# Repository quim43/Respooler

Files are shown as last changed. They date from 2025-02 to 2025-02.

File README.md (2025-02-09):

#Respooler



🚀 **Respooler** es una máquina compacta para rebobinar filamento de impresora 3D de manera eficiente. Está basada en el diseño **V-Spooler**, pero con mejoras como un **motor paso a paso** y un **sensor de filamento** para facilitar su uso.

## 📌 Características

- Diseño compacto y optimizado.
- Soporte para diferentes poleas y correas HDT de 10 mm.
- Motor con ajuste fácil de tensión de correa.
- Eje de bobina más grueso para mayor resistencia.
- Compatible con **Maker's Supply**.
- Sensores que detienen el motor automáticamente cuando se completa el proceso.

## 🛠️ Hardware y Electrónica Necesaria

- Motor **NEMA 17**.
- Sensor de filamento.
- **Arduino Nano** para el control.
- Driver de motor paso a paso.
- Varias piezas impresas en 3D (recomendado **PETG o ABS** para mayor resistencia).
- Tornillos y soportes mecánicos.

Para comprar kits de hardware, visita: [LTS-Design Shop](https://lts-design.com/)

## 🔧 Ensamblaje

1. Instala la base del motor y fija el **NEMA 17** con tornillos M3 x 6.
2. Inserta tu **PCB** (si tienes el kit) y conecta el driver de motor.
3. Conecta los cables del **sensor de filamento** y **botón de inicio** a la PCB.
4. Asegura el regulador de potencia y ajusta la tensión si es necesario.
5. Ensambla el **soporte de la bobina** y el **sistema de poleas**.
6. Ajusta la correa y alinea los engranajes correctamente.
7. Carga el código en el Arduino desde la sección de **Documentación**.

📜 **Diagrama de conexión** disponible en la sección de documentación.

## 📹 Video en Acción

Mira el LTS Respooler en funcionamiento: [YouTube](https://youtu.be/B1Um_I1KRLo)

## ⚙️ Cómo Usarlo

1. Alimenta el filamento desde la bobina superior a través del tubo **PTFE**.
2. El LED derecho se encenderá (si no hay filamento, el motor no inicia).
3. Sujeta el filamento en la bobina inferior y presiona el **botón de inicio**.
4. El motor girará automáticamente hasta completar el proceso.
5. Para detener manualmente, presiona el botón nuevamente.

## 📜 Notas de Impresión 3D

- Las piezas negras deben imprimirse con **PETG o ABS** para mayor durabilidad.
- Algunas piezas requieren **soportes** que deben ser removidos tras la impresión.
- Los tornillos se ajustan directamente en el plástico (sin inserts), ¡no los aprietes demasiado!

## 🏪 Dónde Comprar Kits y Electrónica

Para facilitar la construcción, puedes adquirir diferentes kits en:

🔗 [LTS-Design Store](https://lts-design.com/)

- **PCB solo**: [Comprar aquí](https://lts-design.com/products/lts-respooler-pcb)
- **PCB + Electrónica**: [Comprar aquí](https://lts-design.com/products/lts-respooler-pcb-and-electronics)
- **Power Pack Completo**: [Comprar aquí](https://lts-design.com/products/lts-respooler-power-pack)

## 🛠️ Mejoras y Versiones

### 🔹 V3
- Soporte para **Maker's Supply**.
- Compatibilidad con **correas HDT de 10 mm**.
- Eje de bobina más grueso.
- Ajuste mejorado de la tensión del motor.

### 🔹 V2
- Nuevo diseño de base y estructura para mejor impresión.

### 🔹 V1.5
- Caja de electrónica rediseñada para **mejor ventilación** y menos soportes.

### 🔹 V1
- **Montura de motor ajustable**.

---

📌 **Este proyecto es de código abierto**. Si tienes mejoras, pull requests son bienvenidas. ¡Felices rebobinados! 🎉

---

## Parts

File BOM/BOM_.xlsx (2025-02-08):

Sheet: BOM Respooler
LCSC Part Number | Manufacture Part Number | Manufacturer | Package | Customer # | Description | RoHS | Order Qty. | Product Link
C2932676 | KH-2.54FH-1X15P-H8.5 | Shenzhen Kinghelm Elec | Plugin,P=2.54mm | U1,U2 | 2.54mm Single Row 3A 15P -40℃~+105℃ Direct Insert 1x15P 8.5mm Top Square Hole Plugin,P=2.54mm Female Headers ROHS | yes | 2.00 | https://www.lcsc.com/product-detail/female-headers_shenzhen-kinghelm-elec-kh-2-54fh-1x15p-h8-5_C2932676.html
C25091 | 0402WGF2200TCE | UNI-ROYAL(Uniroyal Elec) | 0402 | R4,R5 | 62.5mW Thick Film Resistors 50V ±100ppm/℃ ±1% 220Ω 0402 Chip Resistor - Surface Mount ROHS | yes | 2.00 | https://www.lcsc.com/product-detail/chip-resistor-surface-mount_uni-royal-uniroyal-elec-0402wgf2200tce_C25091.html
C218370 | ARG05FTC1742N | Viking Tech | 0805 | R2 | 125mW Thin Film Resistor 100V ±25ppm/℃ ±1% 17.4kΩ 0805 Chip Resistor - Surface Mount ROHS | yes | 1.00 | https://www.lcsc.com/product-detail/chip-resistor-surface-mount_viking-tech-arg05ftc1742n_C218370.html
C104683 | RTT062001FTP | RALEC | 1206 | R3 | 250mW Thick Film Resistors 150V ±100ppm/℃ ±1% 2kΩ 1206 Chip Resistor - Surface Mount ROHS | yes | 1.00 | https://www.lcsc.com/product-detail/chip-resistor-surface-mount_ralec-rtt062001ftp_C104683.html
C168095 | FNR6045S101MT | cjiang (Changjiang Microelectronics Tech) | SMD,6x6mm | L1 | 880mA 100uH ±20% 1A SMD,6x6mm Power Inductors ROHS | yes | 1.00 | https://www.lcsc.com/product-detail/power-inductors_cjiang-changjiang-microelectronics-tech-fnr6045s101mt_C168095.html
C476766 | C0805B104K500NT | TORCH | 0805 | C1 | 50V 100nF X7R ±10% 0805 Multilayer Ceramic Capacitors MLCC - SMD/SMT ROHS | yes | 1.00 | https://www.lcsc.com/product-detail/multilayer-ceramic-capacitors-mlcc-smd-smt_torch-c0805b104k500nt_C476766.html
C84983 | RSX301L-30TE25 | ROHM Semicon | SMA(DO-214AC) | D1 | 30V 420mV@3A 3A SMA(DO-214AC) Schottky Diodes ROHS | yes | 1.00 | https://www.lcsc.com/product-detail/schottky-diodes_rohm-semicon-rsx301l-30te25_C84983.html
C273671 | 08053C334K4Z2A | Kyocera AVX | 0805 | C2 | 25V 330nF X7R ±10% 0805 Multilayer Ceramic Capacitors MLCC - SMD/SMT ROHS | yes | 1.00 | https://www.lcsc.com/product-detail/multilayer-ceramic-capacitors-mlcc-smd-smt_kyocera-avx-08053c334k4z2a_C273671.html
C25804 | 0603WAF1002T5E | UNI-ROYAL(Uniroyal Elec) | 0603 | R1 | 100mW Thick Film Resistors 75V ±100ppm/℃ ±1% 10kΩ 0603 Chip Resistor - Surface Mount ROHS | yes | 1.00 | https://www.lcsc.com/product-detail/chip-resistor-surface-mount_uni-royal-uniroyal-elec-0603waf1002t5e_C25804.html
C494815 | EEEFN1C681UP | PANASONIC | SMD | C3 | 680uF 16V 600mA@100kHz 160mΩ@100kHz ±20% SMD Aluminum Electrolytic Capacitors - SMD ROHS | yes | 1.00 | https://www.lcsc.com/product-detail/aluminum-electrolytic-capacitors-smd_panasonic-eeefn1c681up_C494815.html
C2905417 | KH-2.54FH-1X8P-H8.5 | Shenzhen Kinghelm Elec | Plugin,P=2.54mm | U4,U3 | 2.54mm Single Row 3A 8P -40℃~+105℃ Direct Insert 1x8P 8.5mm Top Square Hole Plugin,P=2.54mm Female Headers ROHS | yes | 2.00 | https://www.lcsc.com/product-detail/female-headers_shenzhen-kinghelm-elec-kh-2-54fh-1x8p-h8-5_C2905417.html
C22388458 | BX-PH2.0-2PZZ-R | Bossie | Plugin,P=2mm | LED1,LED2,PUL | 1x2P PH 1 2P 2mm Tin 2 -25℃~+85℃ Copper alloy Direct Insert Plugin,P=2mm Wire To Board Connector ROHS | yes | 3.00 | https://www.lcsc.com/product-detail/wire-to-board-connector_bossie-bx-ph2-0-2pzz-r_C22388458.html
C18077835 | BX-XH2.54-4PZZ | Bossie | Plugin,P=2.54mm | MOTOR,LCD | 1x4P 4P 1 XH Tin 2.54mm 4 -25℃~+85℃ Brass 3A Direct Insert Plugin,P=2.54mm Wire To Board Connector ROHS | yes | 2.00 | https://www.lcsc.com/product-detail/wire-to-board-connector_bossie-bx-xh2-54-4pzz_C18077835.html
C5374805 | WAFER-XH2.54-3PZZ | XUNPU | Plugin,P=2.5mm | ENDSTOP | 1x3P 3P 1 2.54mm 3 -25℃~+85℃ 2A Direct Insert Plugin,P=2.5mm Wire To Board Connector ROHS | yes | 1.00 | https://www.lcsc.com/product-detail/wire-to-board-connector_xunpu-wafer-xh2-54-3pzz_C5374805.html
C544697 | LM2577T-ADJ/NOPB | Texas Instruments | TO-220-5 | U17 | Boost type Adjustable 3A 1.23V~60V 3.5V~40V TO-220-5 DC-DC Converters ROHS | yes | 1.00 | https://www.lcsc.com/product-detail/dc-dc-converters_texas-instruments-lm2577t-adj-nopb_C544697.html
 |  |  |  | TRANSPORT | UPS 3 -5 DIES |  | 1.00
 |  |  |  | ALIEXPRES
----- | Arduino CH340 | Aliexpres | ----- | Arduino nano | Para nano Mini/tipo-c/Micro USB con cargador de arranque controlador rojo Compatible para Arduino CH340 controlador USB 16Mhz ATMEGA328PB | ----- | 1.00 | https://es.aliexpress.com/item/1005006128051481.html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
----- | 17HS4401S | Aliexpres | ----- | Motor | Motor paso a paso con Cable de 1m para impresora 3D CNC, Motor paso a paso de 42 fases, ángulo de paso de 0,9 grados, bajo ruido, 17HS4401S | ----- | 1.00 | https://es.aliexpress.com/item/1005007462616478.html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
----- | 3D 896F endstop | Aliexpres | ----- | ENDSTOP | Interruptor de límite de impresora 3D 896F, accesorios de placa principal, reinicio mecánico-táctil, Endstop | ----- | 2.00 | https://es.aliexpress.com/item/1005005654734137.html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
----- | TMC2209 V3.0 | Aliexpres | ----- | Motor driver | Controlador de Motor paso a paso TMC2209 V3.0, 5 piezas, con 3D disipador de calor para impresora, corriente de Micropasos, pico 2.8A para Reprap Ramps1.4 MKS Gen | ----- | 1.00 | https://es.aliexpress.com/item/1005005351333035.html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
----- | LCD | Aliexpres | ----- | Módulo LCD | Módulo LCD LCD1602 para arduino, pantalla verde azul/amarilla de 16x2 caracteres, PCF8574T PCF8574 IIC I2C, interfaz 5V, 1602 | ----- | 1.00 | https://www.aliexpress.com/gcp/300000512/nnmixupdatev3?productIds=1005006018109299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
----- | Bot | Aliexpres | ----- | Pulsador | Interruptor de botón de enclavamiento de Metal, accesorio redondo de encendido/apagado, impermeable, autoblocante, 4 pines, CC de 2 piezas, 12V/24V | ----- | 1.00 | https://www.aliexpress.com/gcp/300000512/nnmixupdatev3?productIds=1005006018109299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
 |  |  |  | BAMBU LAB
----- | FA003 | FA003 | ----- | FA003 | 4mm Stainless Steel Balls (10PCS) - FA003 | ----- | 1.00 | https://eu.store.bambulab.com/es-es/products/bolas-de-acero-inoxidable?variant=48740440605020
----- | EA028 | EA028 | ----- | EA028 | 608zz P5 Steel Deep Groove Ball Bearings (2PCS) - EA028 | ----- | 7.00 | https://eu.store.bambulab.com/es-es/products/high-performance-bearings?variant=48795653767516
----- | AB005 | AB005 | ----- | AB005 | M3 Carbon Steel Hex Nut (20PCS) - AB005 | ----- | 1.00 | https://eu.store.bambulab.com/es-es/products/hex-nut?variant=48722463129948
----- | AA036 | AA036 | ----- | AA036 | M3x6 SHCS Machine Screw (20PCS) - AA036 | ----- | 2.00 | https://eu.store.bambulab.com/es-es/products/tornillos-para-maquinas-con-cabeza-hueca-m3-shcs-1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
----- | AA159 | AA159 | ----- | AA159 | M3x10 SHCS Machine Screw (20PCS) - AA159 | ----- | 2.00 | https://eu.store.bambulab.com/es-es/products/tornillos-para-maquinas-con-cabeza-hueca-m3-shcs-1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
----- | AA039 | AA039 | ----- | AA039 | M3x16 SHCS Machine Screw (10PCS) - AA039 | ----- | 1.00 | https://eu.store.bambulab.com/es-es/products/tornillos-para-maquinas-con-cabeza-hueca-m3-shcs-1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
----- | EA013 | EA013 | ----- | EA013 | MR85zz Steel Deep Groove Ball Bearings (6PCS) - EA013 | ----- | 1.00 | https://eu.store.bambulab.com/es-es/products/micro-steel-deep-groove-ball-bearings?variant=48828597993820
----- | RD014 | RD014 | ----- | RD014 | HTD 408-3M-10 Timing Belt (1PCS) - RD014 | ----- | 2.00 | https://eu.store.bambulab.com/es-es/products/high-torque-drive-timing-belt?variant=48890105528668
----- | EA035 | EA035 | ----- | EA035 | 6001zz Steel Deep Groove Ball Bearings (2PCS) - EA035 | ----- | 1.00 | https://eu.store.bambulab.com/es-es/products/steel-deep-groove-ball-bearings-1?variant=48828599828828
 |  |  |  |  | TAX |  | 1.00

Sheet: Bost_Proto
LCSC Part Number | Manufacture Part Number | Manufacturer | Customer NO. | Package | Description | RoHS | Order Qty. | Min\Mult Order Qty. | Unit Price(€) | Order Price(€)
C2873969 | KM1E101M0611 | ROQANG | C1 | Plugin | 100uF 25V ±20% 142mA@120kHz Plugin Aluminum Electrolytic Capacitors - Leaded ROHS | YES | 50 | 50\50 | 174 | 87
C109713 | MPP334J2E1305125LC | SRD(Shenzhen Sincerity Tech) | C2 | Plugin | 330nF -40℃~+85℃ ±5% Plugin Polypropylene Film Capacitors (CBB) ROHS | YES | 10 | 10\10 | 516 | 52
C1498450 | EKZH250ETD681MJ16S | NCC(Nippon Chemi-Con) | C3 | Plugin | 680uF 25V 32mΩ ±20% 990mA@120Hz Plugin Aluminum Electrolytic Capacitors - Leaded ROHS | YES | 5 | 5\5 | 2599 | 130
C9119 | 1N5821RLG | onsemi | D1 | DO-201AD | 30V 500mV@3A 3A DO-201AD Schottky Diodes ROHS | YES | 12 | 1\1 | 3095 | 371
C908342 | SLT065125T101KTB | Sunltech Tech | L1 | Plugin | 100uH Magnetic ring inductance ±10% Plugin Color Ring Inductors / Through Hole Inductors ROHS | YES | 2 | 1\1 | 5297 | 106
C172660 | RN16T51742F | TA-I Tech | R2 | Plugin,D2.5xL4.7mm | Metal Film Resistors 17.4kΩ 166.667mW ±100ppm/℃ ±1% Plugin,D2.5xL4.7mm Through Hole Resistors ROHS | YES | 50 | 50\50 | 98 | 49

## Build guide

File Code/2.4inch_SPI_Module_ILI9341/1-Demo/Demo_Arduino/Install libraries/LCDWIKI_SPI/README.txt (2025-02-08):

This is a library for the SPI lcd display.
This library support these lcd controller:
ILI9325 
ILI9328 
ILI9341 
HX8357D 
HX8347G 
HX8347I 
ILI9486 
ST7735S 
SSD1283A

Check out the file of LCDWIKI SPI lib Requirements for our tutorials and wiring diagrams.

These displays use spi bus to communicate, 5 pins are required to interface (MISO is no need).

Basic functionally of this library was origianlly based on the demo-code of Adafruit GFX lib and Adafruit SPITFT lib.  

MIT license, all text above must be included in any redistribution

To download. click the DOWNLOADS button in the top right corner, rename the uncompressed folder LCDWIKI_SPI. Check that the LCDWIKI_SPI folder contains LCDWIKI_SPI.cpp and LCDWIKI_SPI.h

Place the LCDWIKI_SPI library folder your <arduinosketchfolder>/libraries/ folder. You may need to create the libraries subfolder if its your first library. Restart the IDE

Also requires the LCDWIKI_GUI library for Arduino. 
https://github.com/lcdwiki/LCDWIKI_gui

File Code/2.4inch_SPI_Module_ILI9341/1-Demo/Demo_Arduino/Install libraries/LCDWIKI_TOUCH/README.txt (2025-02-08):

This is a library for the touch screen.
This library support these touch IC:
HR2046
XPT2046
 
Check out the file of LCDWIKI TOUCH lib Requirements for our tutorials and wiring diagrams.

These touch screen use 4-wire spi to communicate, 5 pins are required to interface (Need to add the TP_IRQ pin).
Run the touch screen calibration program and put the calibration parameter into the file of cali_para.h after the calibration has passed.

MIT license, all text above must be included in any redistribution

To download. click the DOWNLOADS button in the top right corner, rename the uncompressed folder LCDWIKI_TOUCH. Check that the LCDWIKI_TOUCH folder contains LCDWIKI_TOUCH.cpp and LCDWIKI_TOUCH.h

Place the LCDWIKI_TOUCH library folder your <arduinosketchfolder>/libraries/ folder. You may need to create the libraries subfolder if its your first library. Restart the IDE

Also requires the LCDWIKI_GUI and LCDWIKI_KBV library for Arduino. 
https://github.com/lcdwiki/LCDWIKI_gui
https://github.com/lcdwiki/LCDWIKI_kbv

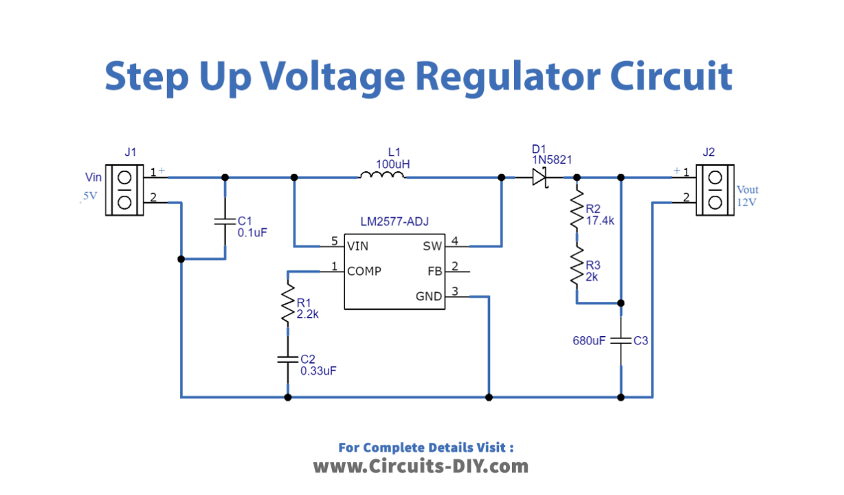
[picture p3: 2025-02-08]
Electronics/Step-Up-Voltage-Regulator-Circuit-IC-LM2577-diagram-schematic-1228x720-2.png

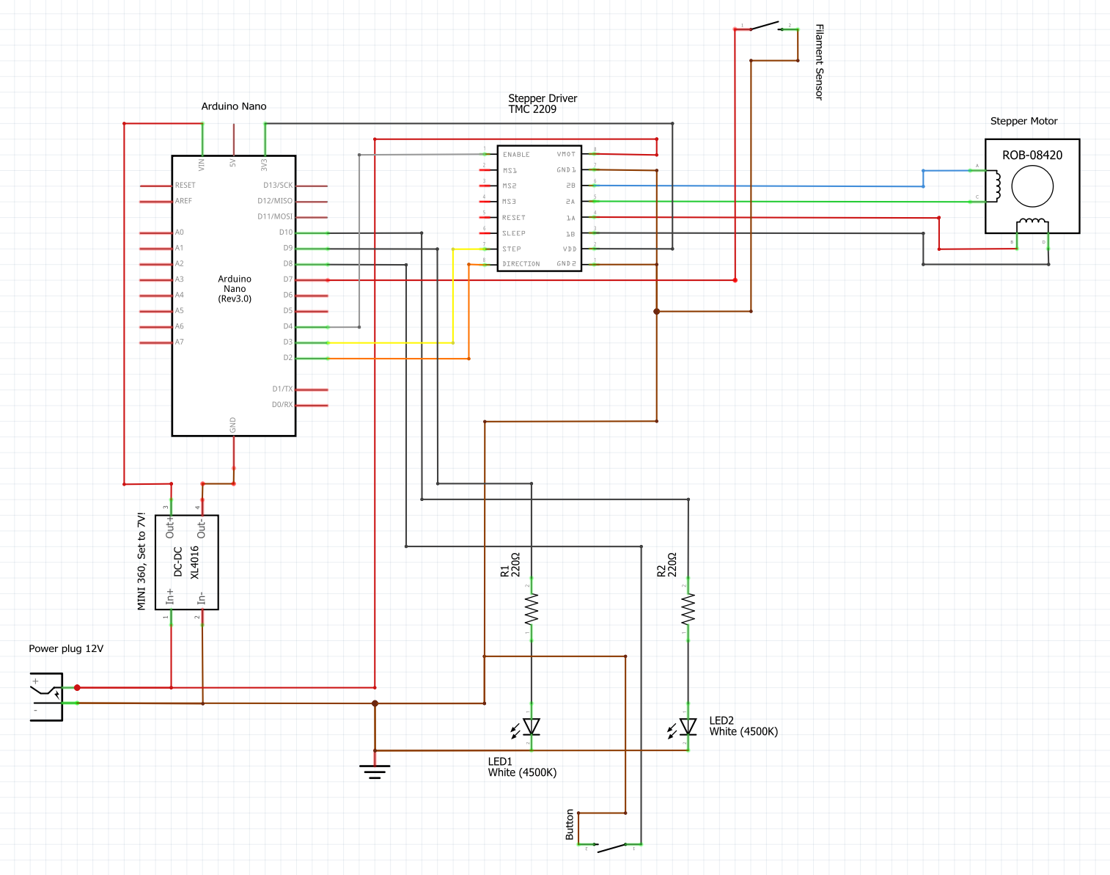
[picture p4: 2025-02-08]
Electronics/Wiring%20Diagram%20LTS%20Respooler.png

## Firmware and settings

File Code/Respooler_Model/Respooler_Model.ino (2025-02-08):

#include "SPI.h"
#include "Adafruit_GFX.h"
#include <AccelStepper.h>
#include "Adafruit_ILI9341.h"

// Pines del motor y LEDs
const int dirPin = 8;      // Pin de dirección del motor
const int stepPin = 9;     // Pin de pasos del motor
const int enablePin = 10;  // Pin de enable del driver
const int ledVerde = A1;   // LED verde (tensión OK)
const int ledBlanco = A1;  // LED blanco (motor funcionando)
const int pulsador = A2;   // Pulsador para activar el motor
const int endstop = 7;     // Endstop para detener el motor

// Crear objeto AccelStepper
AccelStepper motor(AccelStepper::DRIVER, stepPin, dirPin);

// Variables de estado
bool motorActivo = false;
unsigned long tiempoParpadeo = 0;             // Para controlar el parpadeo del LED blanco
const unsigned long intervaloParpadeo = 500;  // Intervalo de parpadeo (500ms)

// Pines para la pantalla TFT
#define TFT_CS A5       // Pin Chip Select
#define TFT_RST A4      // Pin Reset
#define TFT_DC A3       // Pin Data/Command
#define TFT_MOSI 11     // Pin MOSI para SPI
#define TFT_SCK 13      // Pin Clock para SPI
#define TFT_LED A0      // Pin para el backlight de la pantalla
#define TFT_MISO 12     // No usado para TFT
#define GFX_BL TFT_LED  // Pin para controlar el backlight

// Pines de conexión del controlador táctil XPT2046
#define T_CS    2    // Pin Chip Select del controlador táctil
#define T_IRQ   6    // Pin de interrupción del controlador táctil (opcional)

// Velocidad del SPI (reducida para mejor estabilidad)
#define SPI_SPEED 20000000  // 40 MHz (puedes probar valores más bajos si sigue habiendo problemas)

// Crear una instancia de la pantalla
// Adafruit_ILI9341 tft = Adafruit_ILI9341(TFT_CS, TFT_DC, TFT_RST);
Adafruit_ILI9341 tft = Adafruit_ILI9341(TFT_CS, TFT_DC, TFT_MOSI, TFT_SCK, TFT_RST, TFT_MISO);
// XPT2046_Touchscreen ts(T_CS, -1);  // No usar interrupciones para facilitar la calibración

void setup() {
  // Configuración de los pines del motor
  delay(500);
  //setCpuFrequencyMhz(240);

  pinMode(TFT_LED, OUTPUT);
  pinMode(ledVerde, OUTPUT);
  pinMode(ledBlanco, OUTPUT);
  pinMode(pulsador, INPUT_PULLUP);
  pinMode(endstop, INPUT_PULLUP);
  pinMode(enablePin, OUTPUT);  // Pin Enable del driver
  pinMode(dirPin, OUTPUT);     // Configurar dirPin como salida
  pinMode(stepPin, OUTPUT);    // Configurar stepPin como salida

  digitalWrite(TFT_LED, HIGH);

  // Inicializar la pantalla táctil

  // Encender el LED verde indicando que hay tensión
  digitalWrite(ledVerde, HIGH);

  // Desactivar el motor al inicio
  digitalWrite(enablePin, HIGH);  // Desactivar el driver (Enable es activo en LOW)

  // Configurar aceleración y velocidad del motor
  motor.setMaxSpeed(5000);     // Establecer velocidad máxima del motor
  motor.setAcceleration(200);  // Establecer aceleración del motor

  // Iniciar comunicación serie
  delay(800);
  Serial.begin(9600);
  Serial.println("Iniciando ILI9341...");

  // Añadir un pequeño retraso antes de inicializar la pantalla

  // Inicializar la pantalla con una velocidad SPI ajustada
  tft.begin(SPI_SPEED);

  // Añadir otro retraso después de la inicialización
  delay(500);

  // Establecer la rotación de la pantalla (opcional, 0 a 3)
  tft.setRotation(3);
  delay(500);
  // Rellenar la pantalla de negro
  tft.fillScreen(ILI9341_BLACK);

  // Dibujar un rectángulo de prueba
  // tft.fillRect(10, 10, 100, 50, ILI9341_RED);  // Un rectángulo rojo en la esquina superior izquierda
  delay(500);
  // Establecer el color del texto y el fondo
  tft.setTextColor(ILI9341_WHITE);  // Texto blanco
  tft.setTextSize(5);               // Tamaño de texto
  tft.setCursor(25, 100);
  tft.println("RESPOOLER");

  delay(500);
  tft.setTextColor(ILI9341_WHITE);  // Texto blanco
  tft.setTextSize(3);               // Tamaño de texto
  tft.setCursor(95, 160);
  tft.println("By Quim");
  delay(500);

  Serial.println("Prueba completada.");
}

void loop() {
  // Control del motor y LEDs
  if (digitalRead(pulsador) == LOW && digitalRead(endstop) == HIGH) {
    if (!motorActivo) {
      motorActivo = true;
      digitalWrite(enablePin, LOW);  // Activar el driver (Enable es activo en LOW)
      motor.setSpeed(-4000);         // Velocidad continua (ajusta según necesidad)
      digitalWrite(ledBlanco, LOW);  // Apagar LED blanco momentáneamente (inicia el parpadeo)
    }
    motor.runSpeed();      // El motor gira indefinidamente
    parpadearLedBlanco();  // El LED blanco parpadea mientras el motor funciona
    
  } else {
    if (motorActivo) {
      motorActivo = false;
      motor.stop();                   // Detener el motor
      digitalWrite(enablePin, HIGH);  // Desactivar el driver (Enable es activo en LOW)
      digitalWrite(ledBlanco, HIGH);  // LED blanco fijo indicando que el motor se ha detenido
    }
  }
}

// Función para parpadear el LED blanco
void parpadearLedBlanco() {
  unsigned long tiempoActual = millis();
  if (tiempoActual - tiempoParpadeo >= intervaloParpadeo) {
    tiempoParpadeo = tiempoActual;
    // Cambiar el estado del LED para hacer el efecto de parpadeo
    digitalWrite(ledBlanco, !digitalRead(ledBlanco));
  }
}

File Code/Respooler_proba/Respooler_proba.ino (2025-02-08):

#include "SPI.h"
#include "Adafruit_GFX.h"
#include <AccelStepper.h>
#include "Adafruit_ILI9341.h"
#include "XPT2046_Touchscreen.h"

// Incluir las imágenes
#include "bambu_lab.h"
#include "sunluxl.h"
#include "sunlu.h"
#include "rpbq.h"
#include "cb.h"
#include "c.h"

#define TFT_LED        A0
const int ledVerde =   A1;
const int ledBlanco =  A1;
const int pulsador =   A2;
#define TFT_DC         A3
#define TFT_RST        A4
#define TFT_CS         A5

#define T_CS           2
const int endstop =    7;
const int dirPin =     8;
const int stepPin =    9;
const int enablePin = 10;

// Configuración de SPI y pantalla
#define SPI_SPEED 20000000

Adafruit_ILI9341 tft = Adafruit_ILI9341(TFT_CS, TFT_DC, TFT_RST);
AccelStepper motor(AccelStepper::DRIVER, stepPin, dirPin);
XPT2046_Touchscreen ts(T_CS, -1);

// Variables de estado
bool motorActivo = false;
bool pantallaActiva = true; 
bool estadoPulsador = HIGH; // Estado actual del pulsador
bool estadoPulsadorAnterior = HIGH; // Estado anterior del pulsador

unsigned long tiempoParpadeo = 0;
const unsigned long intervaloParpadeo = 500;

String bobinaSeleccionada =   "";
String materialSeleccionado = "";

float longitudTotalFilamento = 0.0;
float densidadMaterial =       0.0;
float diametroInterno =        0.0;
float pesoFilamento =          0.0;
long pasosAcumulados =           0;

/*
###############################################
*/
void mostrarMensajeInicio() {
  pantallaActiva = true;
  longitudTotalFilamento = 0;
  pesoFilamento = 0;

  // Dibujar la imagen de inicio en la pantalla
  tft.fillScreen(ILI9341_BLACK);
  tft.drawRGBBitmap(0, 0, rpbq, 320, 240);
  // delay(3500);  // Pausa inicial para mostrar la imagen
  
  // Esperar hasta que no haya ningún toque detectado (por si queda alguno residual)
  while (ts.touched()) {
    delay(100);
  }

  // Esperar un toque para avanzar
  Serial.println("Esperando toque en la imagen...");
  while (!ts.touched()) {
    delay(100);  // Pausa breve para evitar un bucle continuo
  }

  delay(500);  // Pausa adicional para evitar toques repetidos
  cargarBobines();
}


void cargarBobines(){
  pantallaActiva = false;
  tft.fillScreen(ILI9341_BLACK);
  tft.drawRGBBitmap(0, 0, cb, 320, 240);
  while (digitalRead(pulsador) == HIGH){} // && digitalRead(endstop) == LOW 
  delay(500);
  pantallaActiva = true;
  mostrarMenuBobina();
  }

void mostrarMenuBobina() {
  tft.fillScreen(ILI9341_BLACK);
  tft.setTextColor(ILI9341_WHITE);
  tft.setTextSize(2);
  tft.setCursor(20, 20);
  tft.println("Selecciona una bobina:");
  tft.drawRGBBitmap(15, 80, bambu_lab, 90, 90);  // Imagen Bambu Lab
  tft.drawRGBBitmap(115, 80, sunlu, 90, 90);     // Imagen Sunlu
  tft.drawRGBBitmap(215, 80, sunluxl, 90, 90);   // Imagen Sunlu XL
  }

void manejarTouch(int x, int y) {
  if (x > 25 && x < 115 && y > 80 && y < 170) {
    bobinaSeleccionada = "Bambu Lab";
    diametroInterno = 55.0;
    seleccionarMaterial();
  } else if (x > 125 && x < 215 && y > 80 && y < 170) {
    bobinaSeleccionada = "Sunlu";
    diametroInterno = 54.4;
    seleccionarMaterial();
  } else if (x > 225 && x < 315 && y > 80 && y < 170) {
    bobinaSeleccionada = "Sunlu XL";
    diametroInterno = 7.25;
    seleccionarMaterial();
    }
  }

void seleccionarMaterial() {
  tft.fillScreen(ILI9341_BLACK);
  tft.setTextColor(ILI9341_WHITE);
  tft.setTextSize(2);
  tft.setCursor(20, 20);
  tft.println("Selecciona el material:");
  tft.setCursor(50, 80); tft.println("PLA");
  tft.setCursor(50, 140); tft.println("PETG");
  tft.setCursor(50, 200); tft.println("ABS");

  while (true) {
    if (ts.touched()) {
      TS_Point p = ts.getPoint();
      int x_mapped = map(p.x, 689, 3700, 0, 320);
      int y_mapped = map(p.y, 3418, 746, 0, 240);
      if (x_mapped > 50 && x_mapped < 150) {
        if (y_mapped > 80 && y_mapped < 120) { materialSeleccionado = "PLA"; densidadMaterial = 1.24; break; }
        else if (y_mapped > 140 && y_mapped < 180) { materialSeleccionado = "PETG"; densidadMaterial = 1.27; break; }
        else if (y_mapped > 200 && y_mapped < 240) { materialSeleccionado = "ABS"; densidadMaterial = 1.04; break; }
        }
      }
    }
    confirmarSeleccion();
  }

void confirmarSeleccion() {
  tft.fillScreen(ILI9341_BLACK);
  tft.setTextColor(ILI9341_WHITE);
  tft.setTextSize(2);
  tft.setCursor(20, 20); tft.println("Confirma seleccion:");
  tft.setCursor(20, 60); tft.print("Bobina: "); tft.println(bobinaSeleccionada);
  tft.setCursor(20, 100); tft.print("Material: "); tft.println(materialSeleccionado);

  tft.fillRect(20, 160, 100, 50, ILI9341_GREEN); tft.setCursor(25, 175); tft.setTextSize(2); tft.println("Aceptar");
  tft.fillRect(140, 160, 100, 50, ILI9341_RED); tft.setCursor(145, 175); tft.println("Cancelar");

  while (true) {
    if (ts.touched()) {
      TS_Point p = ts.getPoint();
      int x_mapped = map(p.x, 689, 3700, 0, 320);
      int y_mapped = map(p.y, 3418, 746, 0, 240);
      if (x_mapped > 20 && x_mapped < 120 && y_mapped > 160 && y_mapped < 210) { 
        verificarCargaBobina(); 
        break; 
      } else if (x_mapped > 140 && x_mapped < 240 && y_mapped > 160 && y_mapped < 210) { 
        mostrarMenuBobina(); 
        return; 
        }
      }
    }
  }

void verificarCargaBobina() {
  pantallaActiva = false;
  tft.fillScreen(ILI9341_BLACK);
  tft.drawRGBBitmap(0, 0, c, 320, 240);
  delay(1500);
  iniciarMotor();
  }

void iniciarMotor() {
  motorActivo = true;
  digitalWrite(enablePin, LOW);
  motor.setSpeed(2000);
  digitalWrite(ledBlanco, LOW);
  digitalWrite(TFT_LED, LOW);
  pantallaActiva = false;

  // Ejecuta el motor hasta que se detenga por el endstop o el pulsador
  while (motorActivo) {
    motor.runSpeed();
    pasosAcumulados++;
    actualizarCalculos();
    parpadearLedBlanco();

    if (digitalRead(endstop) == LOW || digitalRead(pulsador) == HIGH) {
      detenerMotor();
      }
    }
  }

void detenerMotor() {
  motorActivo = false;
  motor.stop();
  digitalWrite(enablePin, HIGH);
  digitalWrite(ledBlanco, HIGH);
  digitalWrite(TFT_LED, HIGH);
  mostrarResultadosFinales();
  }

void actualizarCalculos() {
  float diametroFilamento = 1.75;
  float areaSeccionFilamento = PI * pow(diametroFilamento / 2, 2);
  float diametroEngranajeMotor = 18;
  float diametroEngranajePlato = 52;
  float ratioEngranajes = diametroEngranajePlato / diametroEngranajeMotor;
  float pasosPorVuelta = 200;
  float longitudPorVueltaPlato = PI * diametroInterno;

  float vueltasTotales = pasosAcumulados / (pasosPorVuelta * ratioEngranajes);
  longitudTotalFilamento = vueltasTotales * longitudPorVueltaPlato / 1000;
  pesoFilamento = longitudTotalFilamento * areaSeccionFilamento * densidadMaterial;
  }
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
